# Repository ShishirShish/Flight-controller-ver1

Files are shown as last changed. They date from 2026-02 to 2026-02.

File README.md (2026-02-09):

🛩️ Flight Controller – Custom STM32-Based Design
This repository contains the complete hardware design of a custom STM32-based flight controller, intended for multirotor UAVs and embedded control applications.
The project focuses on robust power design, precise sensor integration, and clean signal routing, suitable for research, academic, and prototyping use.

📌 Features Overview
Microcontroller: STM32F446RETx
Sensors:
6-axis IMU (Accelerometer + Gyroscope)
Barometric pressure sensor
Clocking: External 8 MHz crystal
Power:
USB-powered input
Onboard 3.3 V LDO regulation
Proper filtering and decoupling

Interfaces:

USB (device)
I²C
SPI
UART
CAN

SWD (programming & debugging)

Motor Control:
PWM outputs for ESCs

Timer-based channels

Designed in: KiCad 9.0.6

🧠 Hardware Architecture
1️⃣ Main Controller

STM32F446RE

External 8 MHz crystal with 20 pF load capacitors

SWD interface for debugging and flashing

Proper VCAP, VDDA, and decoupling network

2️⃣ Sensors
IMU (Accelerometer + Gyro)

I²C interface

Dedicated local decoupling capacitors

Pull-up resistors on SDA/SCL

Interrupt pins routed to MCU

Barometer

I²C interface

Configurable I²C address

Separate power filtering

3️⃣ Power Supply

USB 5 V input

Fuse and reverse protection

Low-noise 3.3 V LDO regulator

Power indication LED

Proper bulk and ceramic capacitors

4️⃣ ESC & PWM Outputs

Timer-based PWM outputs

Dedicated headers for ESC signal + power

Designed to support multirotor configurations

5️⃣ Communication Interfaces

USB (DFU / CDC capable)

Multiple UARTs

SPI (sensor expansion)

CAN bus

GPIO expansion headers

🔌 Pin Highlights
Interface	Purpose
TIM2 / TIM3	PWM outputs for ESCs
I2C1 / I2C3	IMU & Barometer
USB FS	Programming / telemetry
SWD	Debugging
CAN	External communication
ADC	Voltage / analog sensing
🧪 Design Considerations

Extensive decoupling and filtering

Ferrite bead isolation for analog supply

RC low-pass filters for ADC inputs

Separate sensor and digital domains

Designed with noise-sensitive IMU placement in mind

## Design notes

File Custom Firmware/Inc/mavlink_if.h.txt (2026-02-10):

#pragma once
#include "mavlink.h"

void mavlink_init(void);
void mavlink_send_heartbeat(void);
void mavlink_send_attitude(float roll, float pitch, float yaw);
void mavlink_process(void);

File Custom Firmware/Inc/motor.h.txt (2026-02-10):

#pragma once
#include <stdint.h>
#include "fc_config.h"

typedef enum {
    MOTOR_STOPPED,
    MOTOR_ARMED
} motor_state_t;

void motor_init(void);
void motor_update(void);
void motor_stop_all(void);

void motor_set(uint8_t motor, uint16_t value);

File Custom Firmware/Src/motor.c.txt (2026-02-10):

#include "motor.h"
#include "dshot.h"
#include "utils.h"

void motor_init(void)
{
    dshot_init(DSHOT600);
}

void motor_set(uint8_t motor, uint16_t value)
{
    value = constrain_u16(value, DSHOT_MIN_THROTTLE, DSHOT_MAX_THROTTLE);
    dshot_send(motor, value);
}

void motor_update(void)
{
    for (uint8_t i = 0; i < MOTOR_COUNT; i++) {
        motor_set(i, (uint16_t)motor_output[i]);
    }
}

void motor_stop_all(void)
{
    for (uint8_t i = 0; i < MOTOR_COUNT; i++) {
        dshot_send(i, 0);
    }
}

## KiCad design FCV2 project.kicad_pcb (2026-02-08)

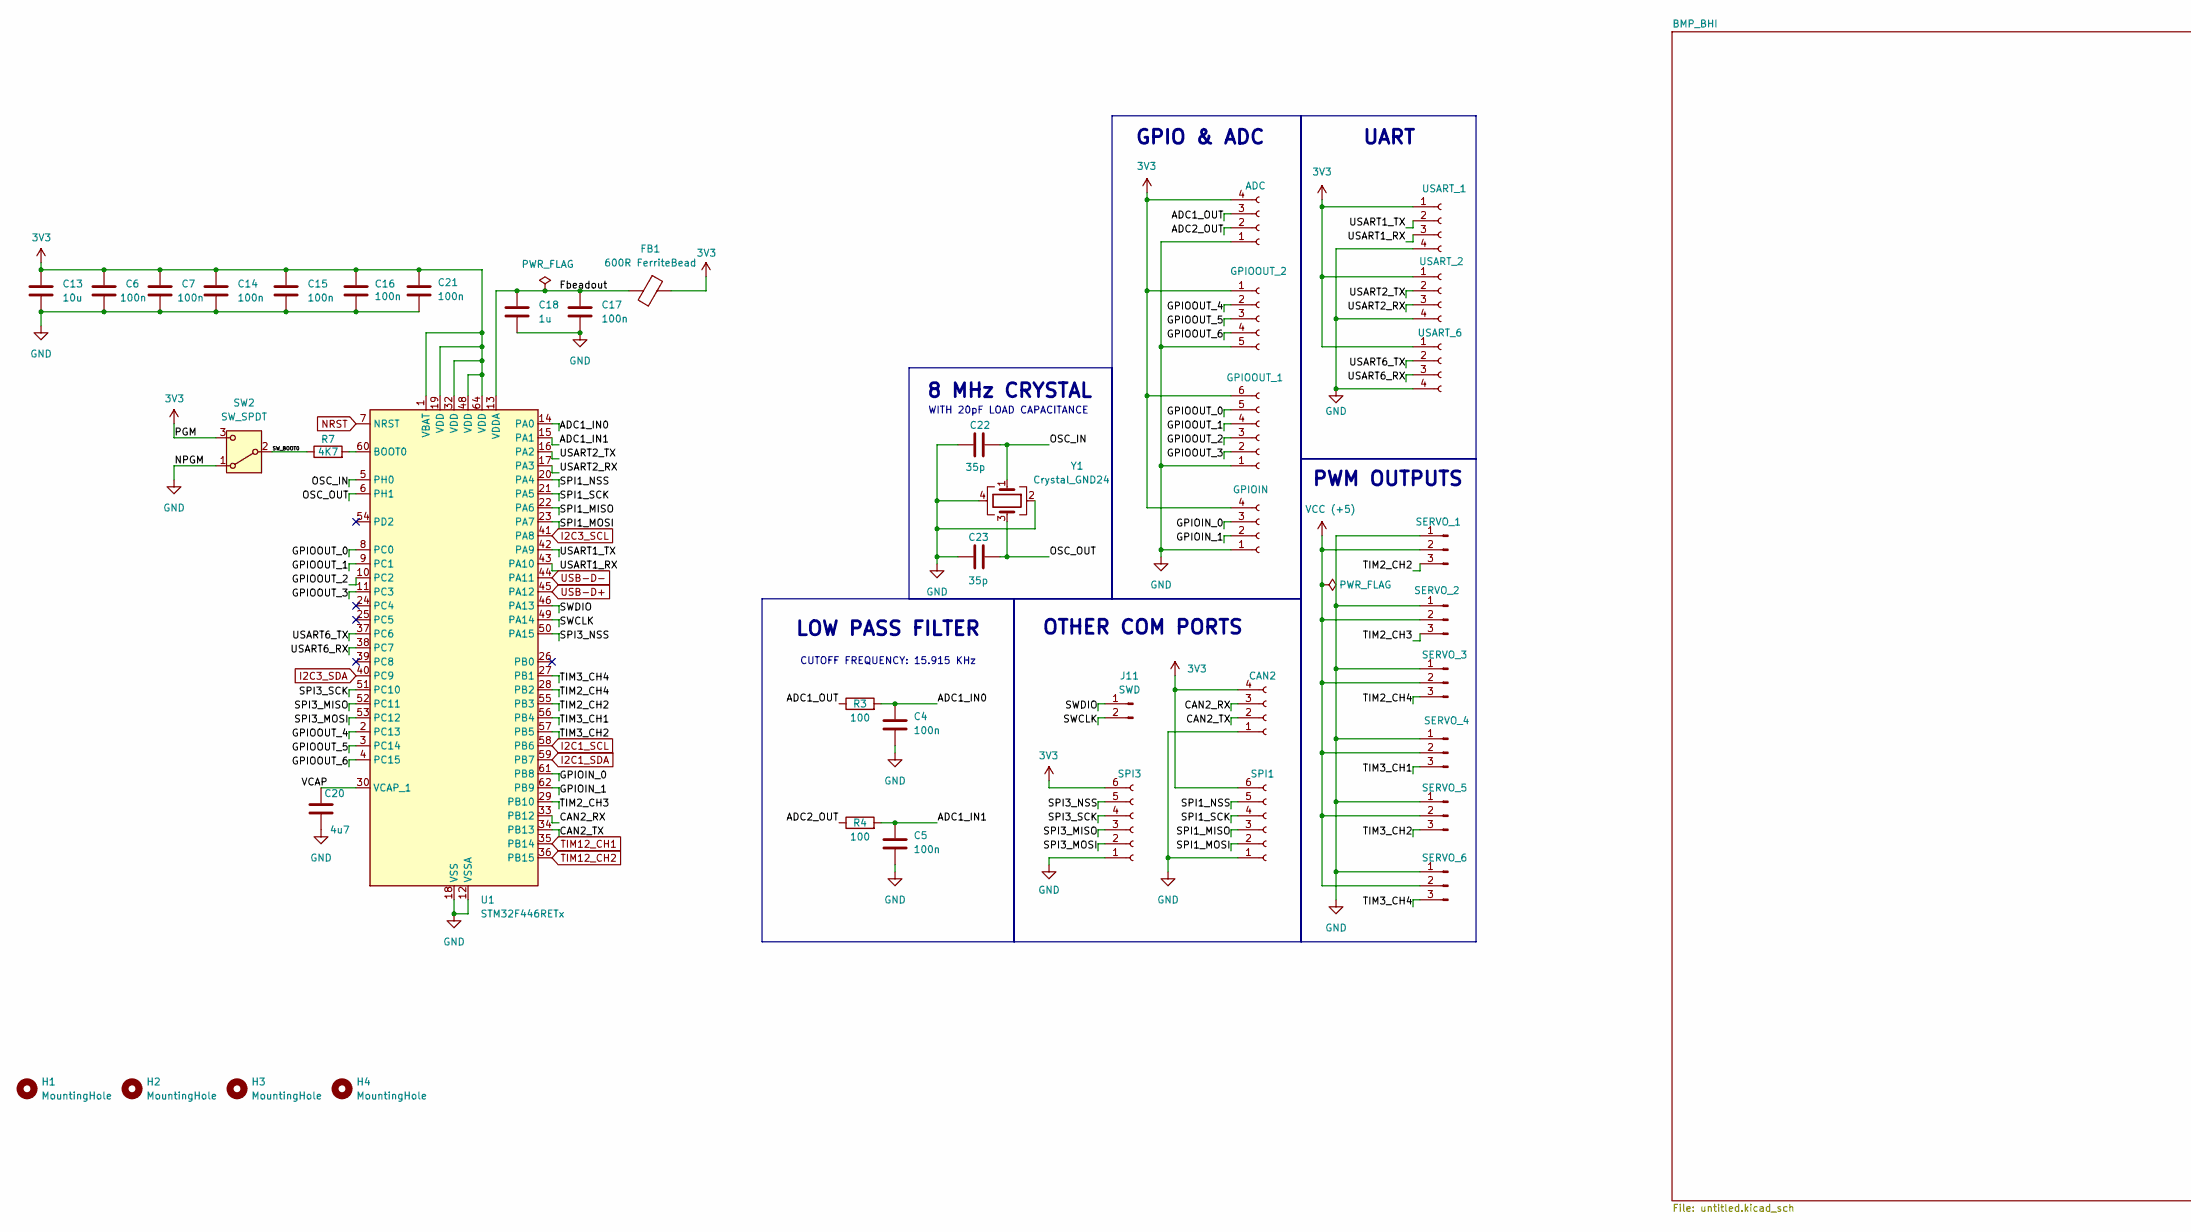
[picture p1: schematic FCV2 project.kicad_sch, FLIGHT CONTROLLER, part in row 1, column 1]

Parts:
C4, C5, C6, C7, C14, C15, C16, C17, C21: 100n; C_0402_1005Metric
C13: 10u; C_0603_1608Metric
C18: 1u; C_0402_1005Metric
C20: 4u7; C_0603_1608Metric
C22, C23: 35p; C_0402_1005Metric
FB1: 600R FerriteBead; L_0603_1608Metric
H1, H2, H3, H4: MountingHole; MountingHole_2.2mm_M2
J1: SPI3; PinSocket_1x06_P2.54mm_Vertical
J2: GPIOOUT_1; PinSocket_1x06_P2.54mm_Vertical
J3: USART_1; PinSocket_1x04_P2.54mm_Vertical
J4: GPIOIN; PinSocket_1x04_P2.54mm_Vertical
J5: ADC; PinSocket_1x04_P2.54mm_Vertical
J6: USART_2; PinSocket_1x04_P2.54mm_Vertical
J7: USART_6; PinSocket_1x04_P2.54mm_Vertical
J8: SERVO_1; PinHeader_1x03_P2.54mm_Vertical
J9: SERVO_2; PinHeader_1x03_P2.54mm_Vertical
J10: GPIOOUT_2; PinSocket_1x05_P2.54mm_Vertical
J11: SWD; PinSocket_1x02_P2.54mm_Vertical
J12: SERVO_5; PinHeader_1x03_P2.54mm_Vertical
J13: SERVO_4; PinHeader_1x03_P2.54mm_Vertical
J14: SERVO_6; PinHeader_1x03_P2.54mm_Vertical
J15: SERVO_3; PinHeader_1x03_P2.54mm_Vertical
J17: SPI1; PinSocket_1x06_P2.54mm_Vertical
J18: CAN2; PinSocket_1x04_P2.54mm_Vertical
R3, R4: 100; R_0402_1005Metric
R7: 4K7; R_0402_1005Metric
SW2: SW_SPDT; SW_SPDT_PCM12
U1: STM32F446RETx; LQFP-64_10x10mm_P0.5mm
Y1: Crystal_GND24; Crystal_SMD_3225-4Pin_3.2x2.5mm

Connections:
3V3: C6.1, C7.1, C13.1, C14.1, C15.1, C16.1, C21.2, FB1.1, J1.6, J2.6, J3.1, J4.4, J5.4, J6.1, J7.1, J10.1, J17.6, J18.4, SW2.3 (C), U1.1 (VBAT), U1.19 (VDD), U1.32 (VDD), U1.48 (VDD), U1.64 (VDD); also elsewhere on the board
/ADC1_IN0: C4.2, R3.2, U1.14 (PA0)
/ADC1_IN1: C5.2, R4.2, U1.15 (PA1)
/ADC1_OUT: J5.3, R3.1
/ADC2_OUT: J5.2, R4.1
/CAN2_RX: J18.3, U1.33 (PB12)
/CAN2_TX: J18.2, U1.34 (PB13)
/Fbeadout: C17.1, C18.1, FB1.2, U1.13 (VDDA)
/GPIOIN_0: J4.3, U1.61 (PB8)
/GPIOIN_1: J4.2, U1.62 (PB9)
/GPIOOUT_0: J2.5, U1.8 (PC0)
/GPIOOUT_1: J2.4, U1.9 (PC1)
/GPIOOUT_2: J2.3, U1.10 (PC2)
/GPIOOUT_3: J2.2, U1.11 (PC3)
/GPIOOUT_4: J10.2, U1.2 (PC13)
/GPIOOUT_5: J10.3, U1.3 (PC14)
/GPIOOUT_6: J10.4, U1.4 (PC15)
/OSC_IN: C22.1, U1.5 (PH0), Y1.1
/OSC_OUT: C23.1, U1.6 (PH1), Y1.3
/SPI1_MISO: J17.3, U1.22 (PA6)
/SPI1_MOSI: J17.2, U1.23 (PA7)
/SPI1_NSS: J17.5, U1.20 (PA4)
/SPI1_SCK: J17.4, U1.21 (PA5)
/SPI3_MISO: J1.3, U1.52 (PC11)
/SPI3_MOSI: J1.2, U1.53 (PC12)
/SPI3_NSS: J1.5, U1.50 (PA15)
/SPI3_SCK: J1.4, U1.51 (PC10)
/SWCLK: J11.2, U1.49 (PA14)
/SWDIO: J11.1, U1.46 (PA13)
/SW_BOOT0: R7.1, SW2.2 (B)
/TIM2_CH2: J8.3, U1.55 (PB3)
/TIM2_CH3: J9.3, U1.29 (PB10)
/TIM2_CH4: J15.3, U1.28 (PB2)
/TIM3_CH1: J13.3, U1.56 (PB4)
/TIM3_CH2: J12.3, U1.57 (PB5)
/TIM3_CH4: J14.3, U1.27 (PB1)
/USART1_RX: J3.3, U1.43 (PA10)
/USART1_TX: J3.2, U1.42 (PA9)
/USART2_RX: J6.3, U1.17 (PA3)
/USART2_TX: J6.2, U1.16 (PA2)
/USART6_RX: J7.3, U1.38 (PC7)
/USART6_TX: J7.2, U1.37 (PC6)
/VCAP: C20.1, U1.30 (VCAP_1)
GND: C4.1, C5.1, C6.2, C7.2, C13.2, C14.2, C15.2, C16.2, C17.2, C18.2, C20.2, C21.1, C22.2, C23.2, J1.1, J2.1, J3.4, J4.1, J5.1, J6.4, J7.4, J8.1, J9.1, J10.5, J12.1, J13.1, J14.1, J15.1, J17.1, J18.1, SW2.1 (A), U1.12 (VSSA), U1.18 (VSS), U1.31 (VSS), U1.47 (VSS), U1.63 (VSS), Y1.2, Y1.4; also elsewhere on the board
I2C1_SCL: U1.58 (PB6); also elsewhere on the board
I2C1_SDA: U1.59 (PB7); also elsewhere on the board
I2C3_SCL: U1.41 (PA8); also elsewhere on the board
I2C3_SDA: U1.40 (PC9); also elsewhere on the board
NRST: U1.7 (NRST); also elsewhere on the board
unnamed: R7.2, U1.60 (BOOT0)
TIM12_CH1: U1.35 (PB14); also elsewhere on the board
TIM12_CH2: U1.36 (PB15); also elsewhere on the board
USB-D+: U1.45 (PA12); also elsewhere on the board
USB-D-: U1.44 (PA11); also elsewhere on the board
VCC (+5): J8.2, J9.2, J12.2, J13.2, J14.2, J15.2; also elsewhere on the board

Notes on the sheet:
GPIO & ADC
CUTOFF FREQUENCY: 15.915 KHz
LOW PASS FILTER
UART
PWM OUTPUTS
OTHER COM PORTS
8 MHz CRYSTAL
WITH 20pF LOAD CAPACITANCE

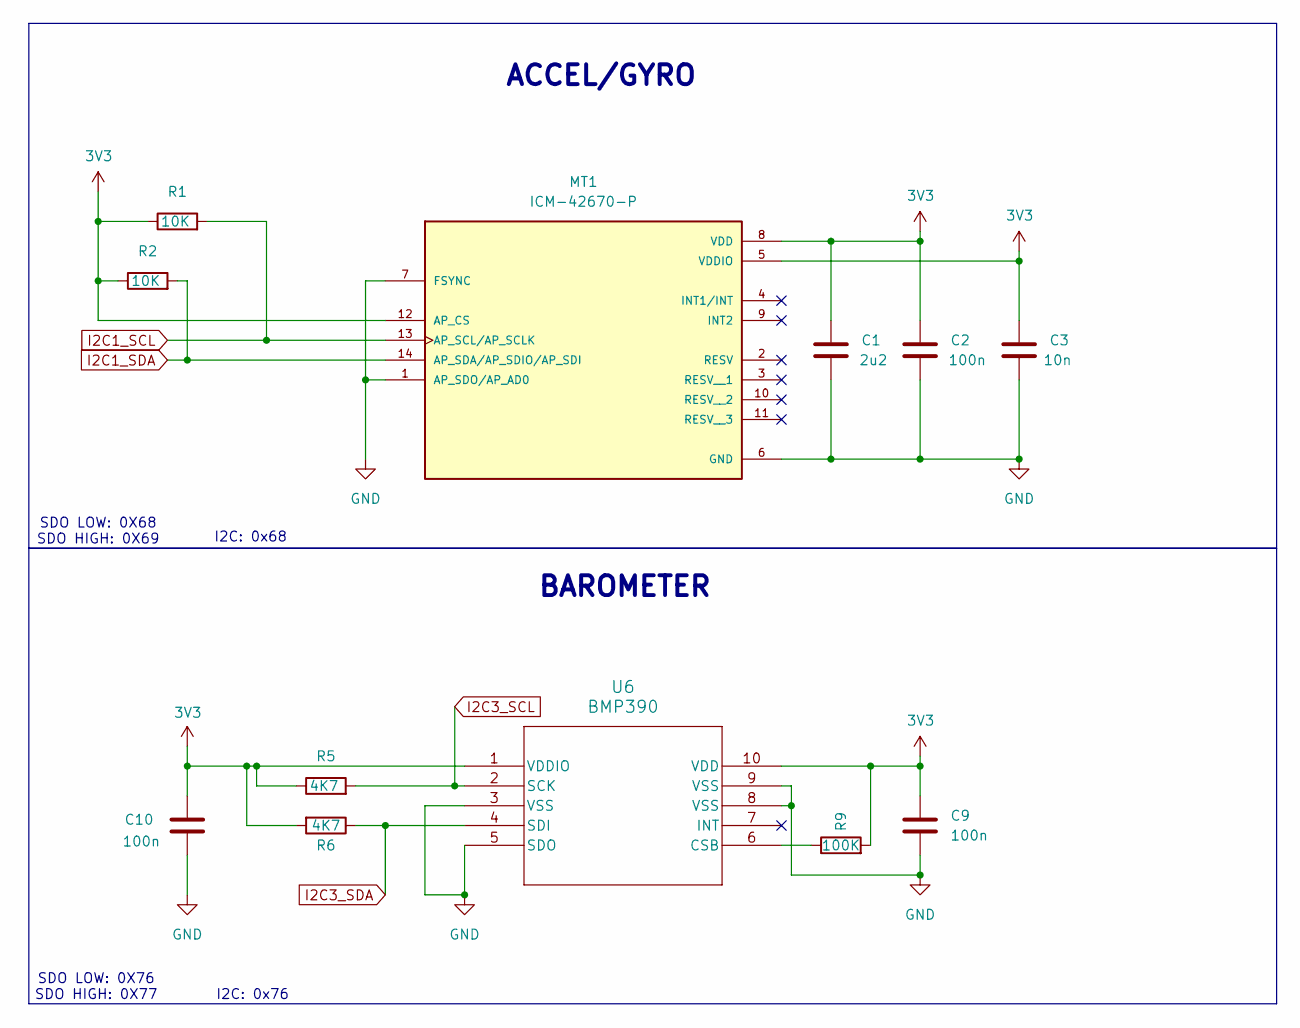
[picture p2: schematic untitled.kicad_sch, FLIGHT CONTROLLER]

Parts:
C1: 2u2; C_0603_1608Metric
C2, C9, C10: 100n; C_0402_1005Metric
C3: 10n; C_0402_1005Metric
MT1: ICM-42670-P; LGA14_2.5X3X0.76_IVS; PARTREV 1.1
R1, R2: 10K; R_0402_1005Metric
R5, R6: 4K7; R_0402_1005Metric
R9: 100K; R_0402_1005Metric
U6: BMP390

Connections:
3V3: C1.1, C2.1, C3.1, C9.1, C10.1, MT1.5 (VDDIO), MT1.8 (VDD), MT1.12 (AP_CS), R1.1, R2.1, R5.1, R6.2, R9.2, U6.1 (VDDIO), U6.10 (VDD); also elsewhere on the board
GND: C1.2, C2.2, C3.2, C9.2, C10.2, MT1.1 (AP_SDO/AP_AD0), MT1.6 (GND), MT1.7 (FSYNC), U6.3 (VSS), U6.5 (SDO), U6.8 (VSS), U6.9 (VSS); also elsewhere on the board
I2C1_SCL: MT1.13 (AP_SCL/AP_SCLK), R1.2; also elsewhere on the board
I2C1_SDA: MT1.14 (AP_SDA/AP_SDIO/AP_SDI), R2.2; also elsewhere on the board
I2C3_SCL: R5.2, U6.2 (SCK); also elsewhere on the board
I2C3_SDA: R6.1, U6.4 (SDI); also elsewhere on the board
unnamed: R9.1, U6.6 (CSB)

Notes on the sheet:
I2C: 0x76
ACCEL/GYRO
SDO LOW: 0X68 SDO HIGH: 0X69
BAROMETER
SDO LOW: 0X76 SDO HIGH: 0X77
I2C: 0x68

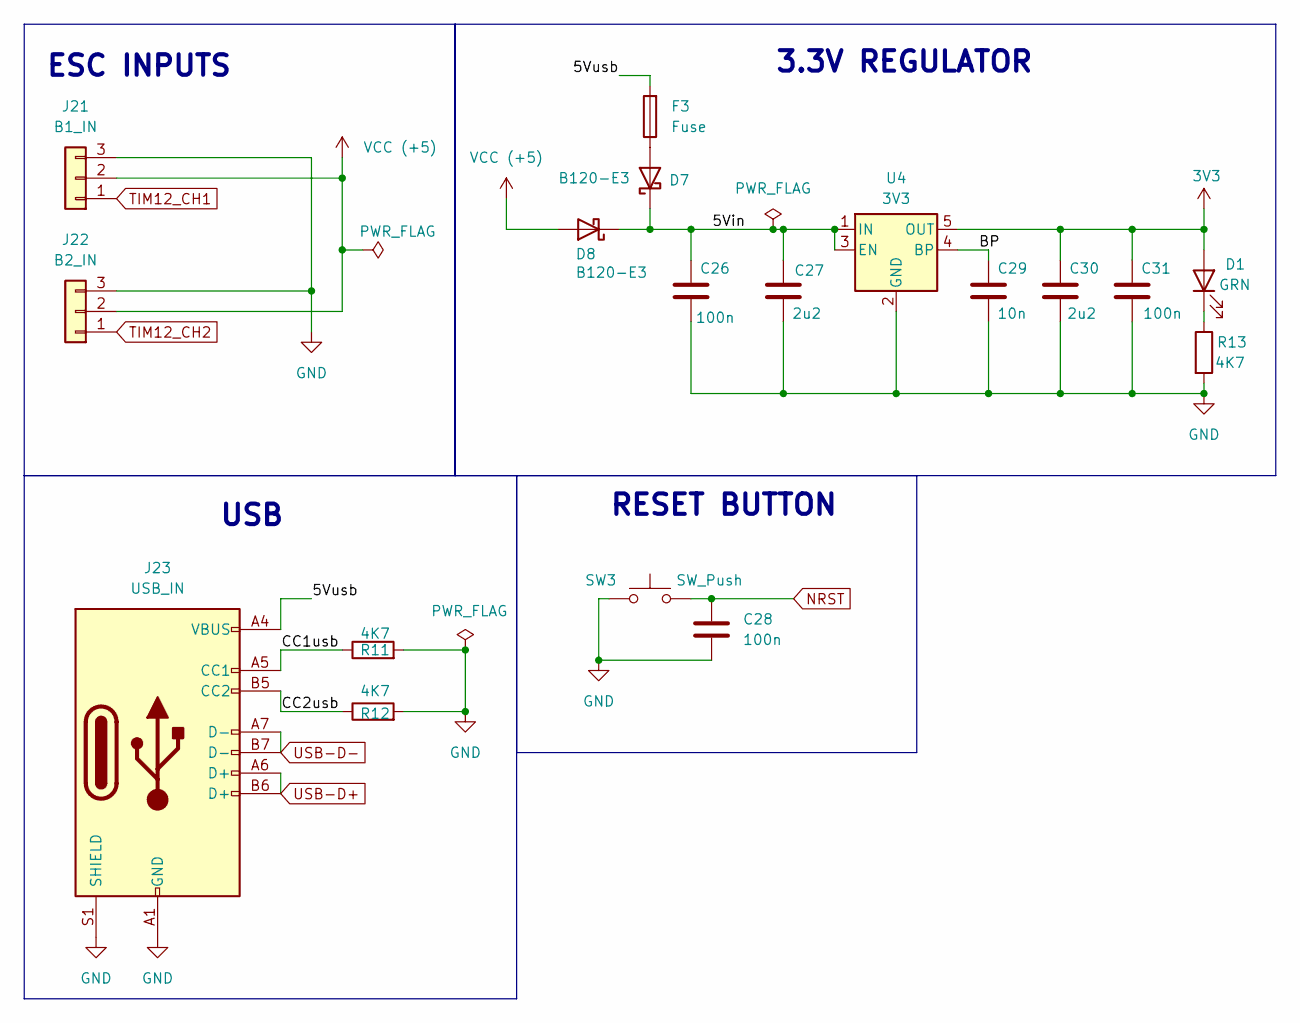
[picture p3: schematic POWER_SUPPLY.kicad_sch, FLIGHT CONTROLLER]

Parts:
C26, C28, C31: 100n; C_0402_1005Metric
C27, C30: 2u2; C_0603_1608Metric
C29: 10n; C_0402_1005Metric
D1: GRN; LED_0603_1608Metric
D7, D8: B120-E3; D_0603_1608Metric
F3: Fuse; Fuse_1206_3216Metric
J21: B1_IN; PinHeader_1x03_P2.54mm_Vertical
J22: B2_IN; PinHeader_1x03_P2.54mm_Vertical
J23: USB_IN; USB_C_Receptacle_GCT_USB4105-xx-A_16P_TopMnt_Horizontal
R11, R12, R13: 4K7; R_0402_1005Metric
SW3: SW_Push; SW_Push_1P1T_NO_6x6mm_H9.5mm
U4: 3V3; SOT-23-5

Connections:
3V3: C30.1, C31.1, D1.2 (A), U4.5 (OUT); also elsewhere on the board
/POWER SUPPLY/5Vin: C26.1, C27.1, D7.1 (K), D8.1 (K), U4.1 (IN), U4.3 (EN)
/POWER SUPPLY/5Vusb: F3.2, J23.A4 (VBUS), J23.A9 (VBUS), J23.B4 (VBUS), J23.B9 (VBUS)
/POWER SUPPLY/BP: C29.1, U4.4 (BP)
/POWER SUPPLY/CC1usb: J23.A5 (CC1), R11.1
/POWER SUPPLY/CC2usb: J23.B5 (CC2), R12.1
GND: C26.2, C27.2, C28.2, C29.2, C30.2, C31.2, J21.3, J22.3, J23.A1 (GND), J23.A12 (GND), J23.B1 (GND), J23.B12 (GND), J23.S1 (SHIELD), R11.2, R12.2, R13.2, SW3.1, U4.2 (GND); also elsewhere on the board
NRST: C28.1, SW3.2; also elsewhere on the board
unnamed: D1.1 (K), R13.1
unnamed: D7.2 (A), F3.1
TIM12_CH1: J21.1; also elsewhere on the board
TIM12_CH2: J22.1; also elsewhere on the board
USB-D+: J23.A6 (D+), J23.B6 (D+); also elsewhere on the board
USB-D-: J23.A7 (D-), J23.B7 (D-); also elsewhere on the board
VCC (+5): D8.2 (A), J21.2, J22.2; also elsewhere on the board

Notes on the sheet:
USB
RESET BUTTON
ESC INPUTS
3.3V REGULATOR

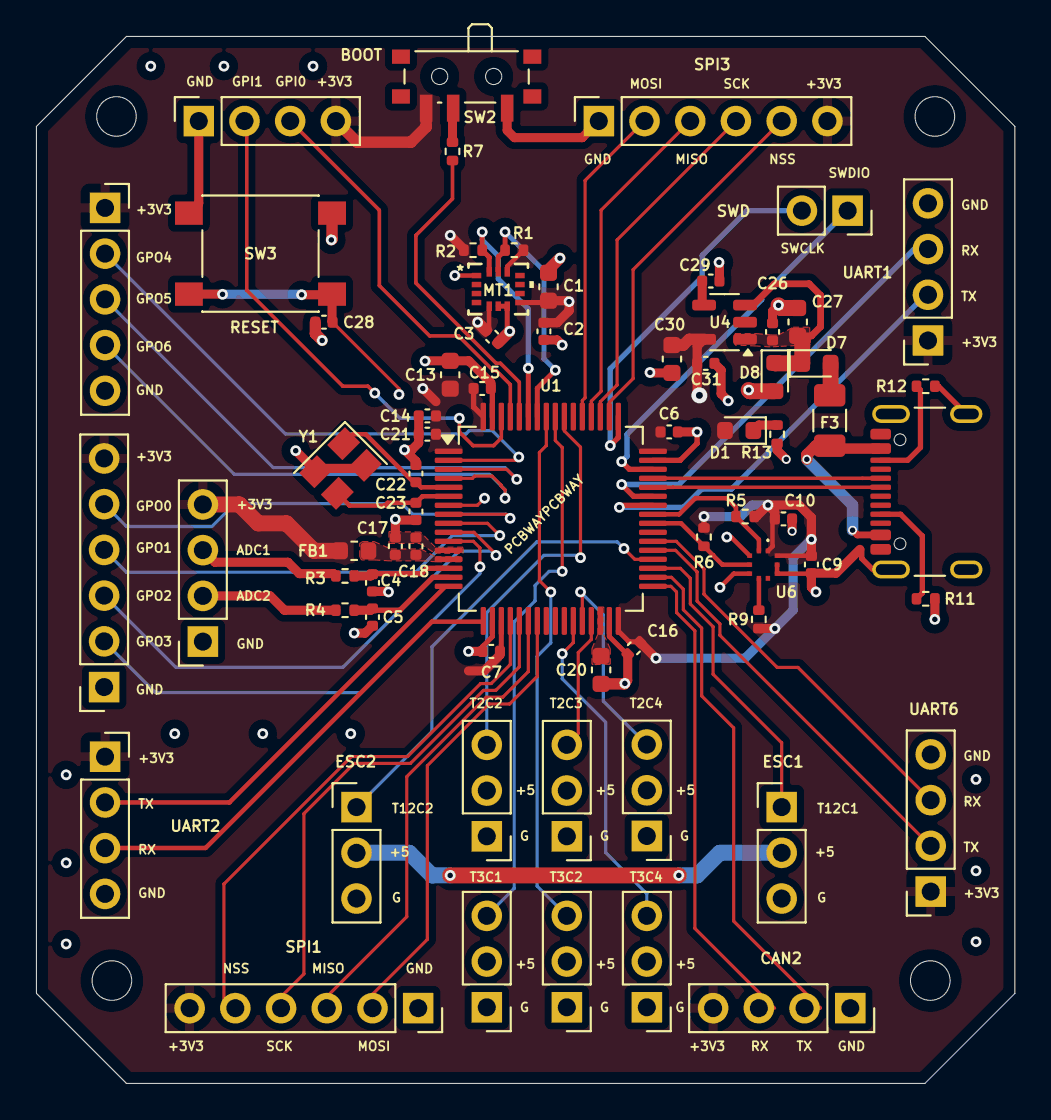
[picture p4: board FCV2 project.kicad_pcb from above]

Board: 4 copper layers, 54.4 x 58.2 mm, 72 parts (0 on the bottom side), 63 nets.

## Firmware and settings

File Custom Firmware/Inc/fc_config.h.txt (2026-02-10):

#pragma once

/* ================= FC CONFIG ================= */

#define FC_CPU_FREQ_HZ     84000000

#define IMU_RATE_HZ        8000
#define PID_RATE_HZ        1000

#define MOTOR_COUNT        6

/* ================= DSHOT ================= */

#define DSHOT600           600
#define DSHOT1200          1200

#define DSHOT_MIN_THROTTLE 48
#define DSHOT_MAX_THROTTLE 2047

/* ================= RC ================= */

#define RC_CHANNELS        16
#define RC_TIMEOUT_MS      300

/* ================= MAVLINK ================= */

#define MAV_SYS_ID         1
#define MAV_COMP_ID        200

/* ================= FAILSAFE ================= */

#define FAILSAFE_TIMEOUT_MS 500
